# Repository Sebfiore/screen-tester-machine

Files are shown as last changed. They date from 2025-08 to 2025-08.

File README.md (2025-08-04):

# Screen Tester Machine  

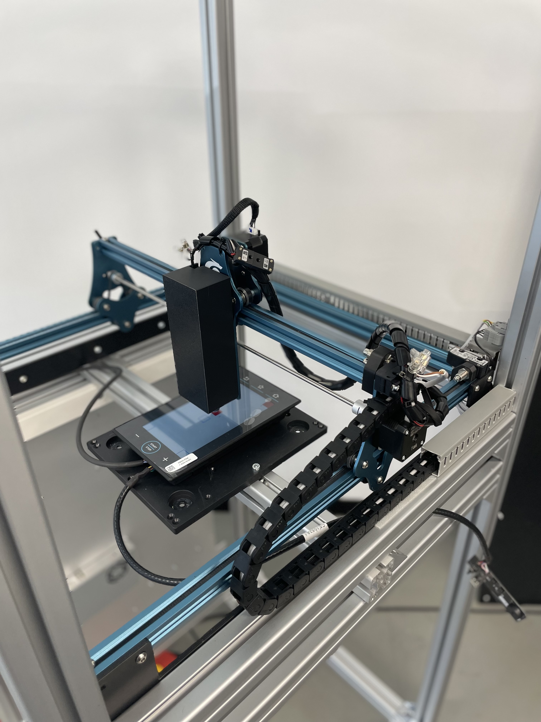
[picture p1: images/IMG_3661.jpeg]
System overview


## Overview

This is an interdisciplinary mechatronics project developed during an internship in the validation department of an Italian electronics company, in collaboration with the University of Padua. It automates the testing of capacitive touch displays by integrating mechanical, electronic, and embedded software components into a unified system.

The platform features multi-axis motion control using stepper motors and custom firmware running on an LPC1768 microcontroller.  
The firmware, written in embedded C, manages both the working routine and low-level stepper motor control.

The design covers all major functional areas of a mechatronic system:

- **Hardware**: Starting from a modified commercial multi-axis platform, the entire structure was redesigned using 3D models and assembled manually. Two commercial machines were evaluated—a 3D printer and a laser cutting machine. The latter was selected for the final build.
- **Electronics**: Custom drive electronics were developed to ensure reliability and flexibility, replacing the original laser machine’s control board. Two stepper drivers were interfaced with the LPC1768 controller.
- **Software**: Both machine routine logic and stepper motor control functions were developed. Special focus was placed on motor speed control. The final version supports a trapezoidal speed profile, with other options also available.

Ultimately, the core focus of the project is system integration: all components were developed independently, with continuous consideration of their role within the complete system. This is arguably the most critical and complex aspect of any mechatronic design.

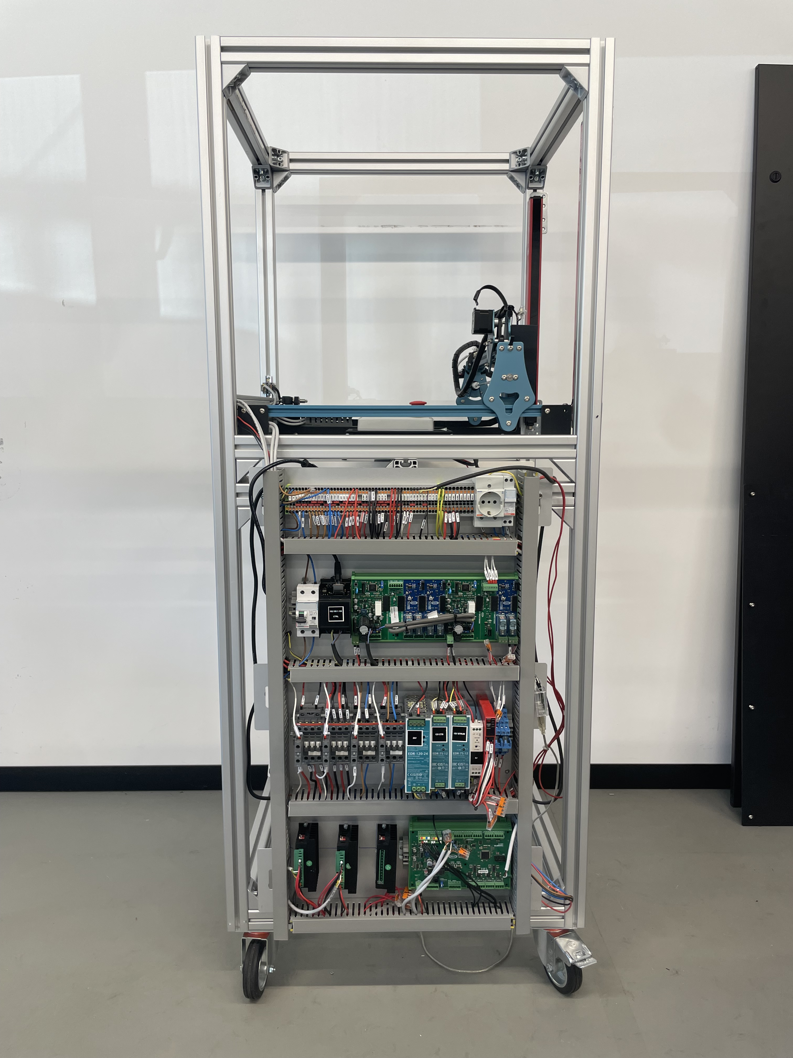
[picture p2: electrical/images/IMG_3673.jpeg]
System overview: Electrical subsystem with TB6600 drivers and LPC1768 control board.


## The Machine

The machine automates the validation process of capacitive touch displays after production. Each display normally requires manual testing—touching a series of points to verify functionality. This machine performs the validation process automatically.  
Future versions aim to further optimize validation by incorporating additional phases such as display programming and automatic color validation.

## Subsystems

### Mechanical

The `mechanical` folder contains descriptions of the system assemblies. Both 3D-printed and machined parts were used. The commercial laser cutter was modified and integrated into an aluminum extrusion frame. All components were designed in 3D prior to assembly.

A key innovation was the development of a compliant mechanism for the touch interface. The touch tip had to press against the display and then release—this was achieved using a solenoid acting on a 3D-printed compliant structure. This solution provided the required flexibility and tight tolerances in a single part.  
The previous traditional system relied on a spring and an aluminum guide, which were more expensive to manufacture and less precise.

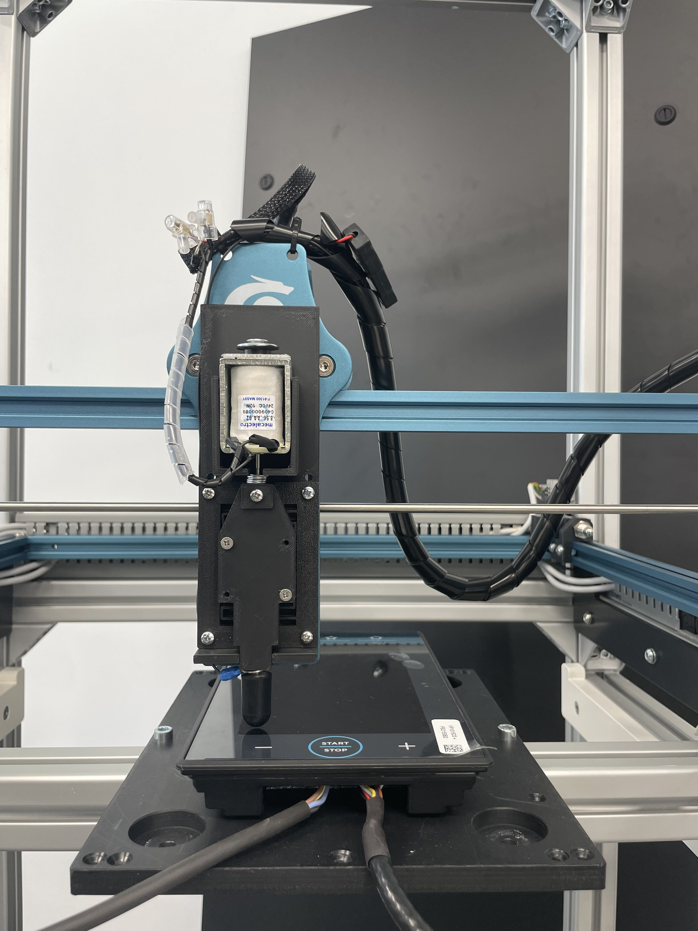
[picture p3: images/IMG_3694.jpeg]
Compliant touch mechanism


### Electrical

This subsystem handles actuation signaling, sensing, and power distribution:
- Dual TB6600 stepper driver control  
- Solenoid actuation with flyback protection  
- Software-selectable endstop inputs via multiplexer  
- Multiple power domains (24V, 12V, 5V) managed by the LPC1768 controller  

### Software / Firmware

The embedded software is written in **C** and runs on a custom LPC1768 (ARM Cortex-M3) controller. It provides real-time orchestration of motion, touch actuation, sensing, and test sequencing for touchscreen validation. See the dedicated section for more detail.

#### Outcomes
- Designed for extensibility: new test patterns, conditional logic, and additional sensors can be integrated without altering the core logic  
- Demonstrates real-time embedded programming, state-machine design, and system-level integration under resource constraints

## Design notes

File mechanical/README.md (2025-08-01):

# Mechanical Subsystem — Screen Tester Machine  

## 1. Introduction

The mechanical subsystem implements the physical interaction layer of the Screen Tester Machine. It comprises the complete structural assembly, interchangeable touch heads in two development stages (conceptual and realized), and a compliant mechanism implemented in two variants to mediate force or alignment. This document describes the design, evolution, and rationale behind each major mechanical element, emphasizing system integration, modularity, and functional trade-offs.

## 2. Overall Assembly

Figure 1: Complete mechanical assembly showing frame, motion stages, touch head interface, and integration points with electrical and actuation subsystems.

*Figure 1* presents the full assembly. The design integrates actuation (from the electrical subsystem), sensing, and the user-contact interface (touch head) into a coherent structure. Key sub-assemblies include the motion positioning stage, the mount for the touch head, compliant interface elements, and the structural frame that ensures repeatability and rigidity under load.

### 2.1 Objectives of the Mechanical Design

- Provide precise and repeatable positioning of the touch interface relative to the display under test.  
- Enable modular swapping and iteration of touch head designs without full system redesign.  
- Isolate and control interaction forces through compliant elements to mimic realistic touches while protecting the device under test.  
- Maintain manufacturability and rapid prototyping capability (e.g., via 3D printing) for iterative development.

## 3. Touch Head Design

The touch head is the contact interface that physically interacts with the capacitive display. Two versions were developed: a conceptual (drawn) version and a realized version using 3D printed components.

### 3.1 Version 1: Conceptual / Drawn Design

Version 1 exists as a detailed design drawing / CAD sketch. It defines:

- Geometry intended to emulate a fingertip or stylus contact patch  
- Mounting interface compatible with the positioning mechanism  
- Intended degrees of freedom and kinematic assumptions  
- Placeholder for compliance or cushioning (if any) in the conceptual stage  

This version served to validate form, fit, and the integration strategy before committing to fabrication.

### 3.2 Version 2: Realized 3D-Printed Touch Head

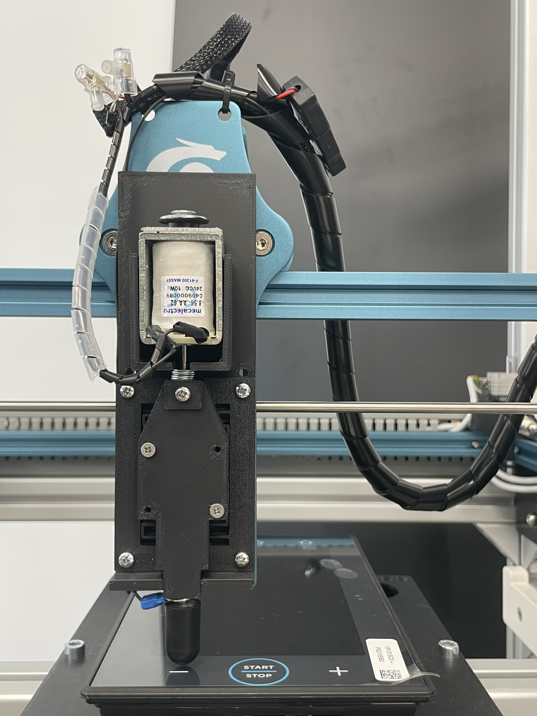
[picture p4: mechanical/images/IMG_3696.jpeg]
Figure 3: Photograph/render of the realized touch head (version 2) fabricated with 3D printed components, showing actual assembly and interface to the compliant mechanism.


Version 2 is the physically fabricated iteration based on the initial concept. Key characteristics:

- **Material:** PLA
- **Post-processing:** (e.g., smoothing, fitting, inserts)  

This realized head was used in empirical testing to assess contact consistency, durability, and repeatability.

## 4. Compliant Mechanism

A compliant mechanism is used to modulate interaction force and absorb minor misalignments between the rigid motion system and the touch surface. Two versions of this mechanism were developed to explore different trade-offs in stiffness, travel, and complexity.

### 4.1 Version 1: Initial Compliant Design

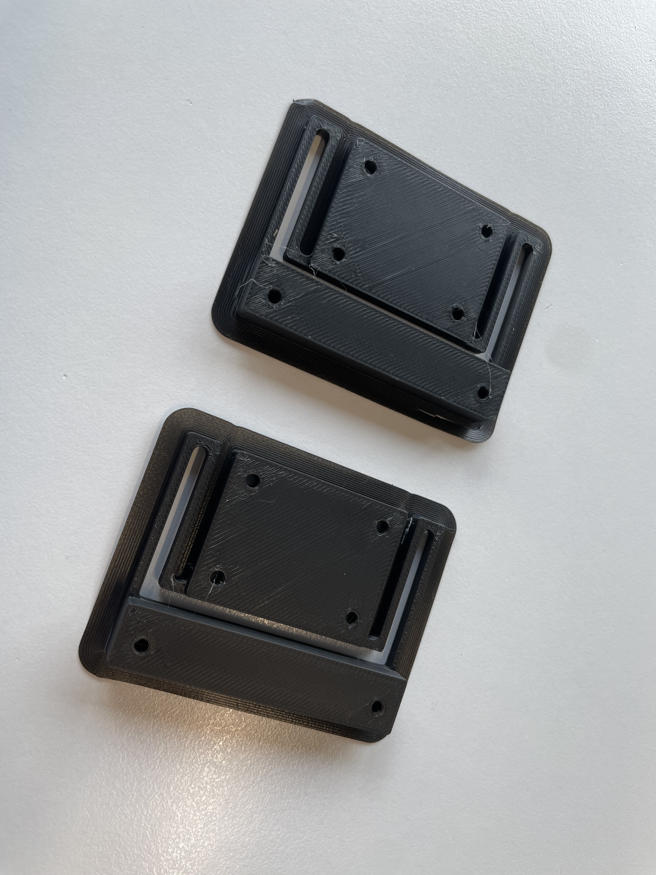
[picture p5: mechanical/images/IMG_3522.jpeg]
Figure 4: Compliant mechanism version 1, illustrating flexural elements and expected deflection under load.


Version 1 utilizes a basic flexure-based geometry designed to allow controlled axial compliance while maintaining lateral constraint. It proved to be too stiff for the scope.

### 4.2 Version 2: Refined Compliant Mechanism

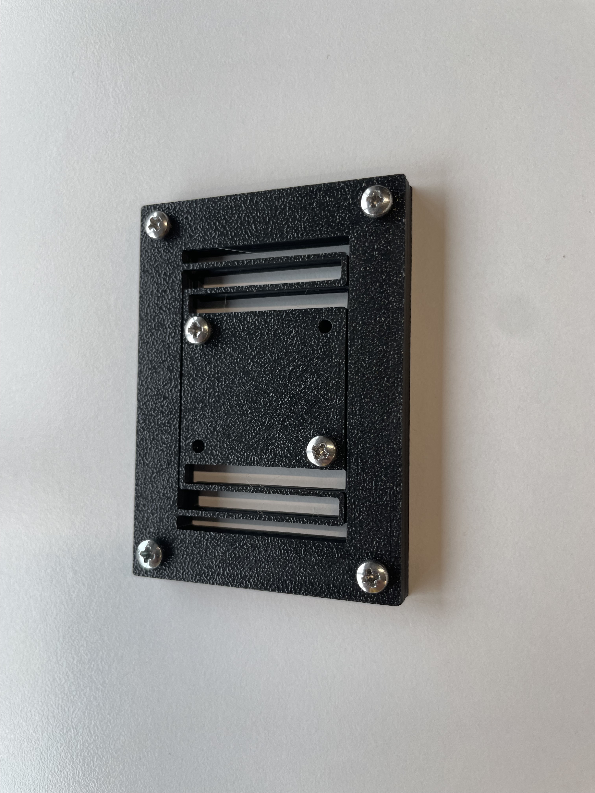
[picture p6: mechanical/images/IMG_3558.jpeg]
Figure 5: Refined compliant mechanism version 2 showing enhancements.


Version 2 represents an evolved design, incorporating lessons from version 1:

- Decreased stiffness
- Integration of mounting features to reduce assembly complexity  

This iteration aimed to balance precision of actuation with robustness over repeated test cycles.

## 5. Mechanical Integration and Interfaces

The touch head and compliant mechanism are mounted to the primary motion stage. The interface between these subsystems was designed for:

- **Quick interchangeability:** Mechanical interfaces (e.g., dovetail, screw boss, snap-fit) allow swapping in the field.  
- **Alignment tolerance:** Compliant elements compensate for small misalignments without degrading measurement fidelity.  

## 6. Design Considerations

- **Prototyping speed:** 3D printing enabled rapid iteration from version 1 to 2 for both touch heads and compliant elements.  
- **Repeatability vs. compliance:** Trade-offs were explicitly evaluated; too much compliance reduces positional accuracy, too little risks damaging the display.  
- **Modularity:** Subsystems are decoupled to allow independent redesign (e.g., new touch head geometries) without retooling the entire assembly.  
- **Manufacturability:** Feature sizes, overhangs, and assembly clearances were constrained by typical FDM printer capabilities.

## 7. Validation Strategy (Descriptive)

Validation of the mechanical subsystem encompassed:

- **Geometric verification:** Ensuring fabricated parts adhered to design dimensions within expected tolerances.  
- **Force profiling:** Measuring the actual contact forces delivered through the compliant mechanism and comparing to target touch profiles.  
- **Durability testing:** Cycling the touch head/compliant interface to observe wear or degradation.  
- **Alignment robustness:** Introducing deliberate offset and measuring if the compliant mechanism compensated without system failure.  
- **Interchangeability checks:** Swapping touch heads and confirming consistent mounting and functional behavior.

## 9. Future Work / Extensions

- Design of alternative touch head geometries (e.g., soft-touch, multi-point)  
- Multi-material compliant mechanisms to introduce tunable damping  
- Embedding sensors (force/pressure) within the compliant interface for closed-loop feedback  

## 10. Conclusion

The mechanical subsystem provides a flexible, modular, and experimentally grounded physical interface for the Screen Tester Machine. Through iterative development of touch heads and compliant mechanisms, the design balances precise actuation, repeatable contact, and protection of the device under test, fulfilling the core goals of the university project.

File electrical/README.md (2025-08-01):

# Electrical Subsystem — Screen Tester Machine  

## 1. Introduction

This document describes the electrical subsystem, its architecture, and its role within the broader system. The focus is on functional description, component interaction, and design rationale.

## 2. System Overview

The electrical subsystem interfaces the mechanical actuation, sensing, and control logic. Its primary responsibilities are:

- Driving two stepper motors to position the stylus/probe via TB6600 drivers  
- Actuating a solenoid for discrete tap interactions  
- Sensing positional limits through endstops with selectable inputs  
- Distributing and conditioning multiple power domains  
- Centralized coordination through a custom LPC1768-based controller  

Control logic, signal multiplexing, and sequencing are consolidated on the custom LPC1768 board. The board issues actuation commands, selects among endstop inputs in software, and orchestrates the timing of movements and interactions.

## 3. Embedded Visual Reference

Figure 1: Electrical subsystem layout including the two TB6600 stepper drivers (bottom left), the custom LPC1768 control board (bottom right), power distribution, and endstop multiplexing.

*Figure 1* shows the physical arrangement of key electrical components and provides contextual insight into signal flow, power routing, and subsystem placement.

## 4. Component Description

### 4.1 Microcontroller and Control Logic

The core intelligence resides on a custom board based on the **LPC1768** microcontroller. This board:

- Generates digital control signals for the stepper drivers (pulse, direction, enable)  
- Drives the solenoid actuator directly via a digital output  
- Samples endstop states through a software-controlled multiplexer  
- Manages synchronization and sequencing for test routines  

Software selection of multiplexer channels allows flexible polling of multiple endstop sensors using minimal input pins.

### 4.2 Stepper Motor Interface

Two stepper motors are interfaced via **TB6600** drivers. Each driver receives:

- **PUL (Pulse):** Step increment signal  
- **DIR (Direction):** Movement direction  
- **ENA (Enable):** Gate to enable/disable outputs  

These signals originate from the LPC1768 digital outputs and are logic-compatible with the TB6600 modules, assuming a shared 5V reference. Signal integrity is maintained by appropriate routing and respecting timing requirements inherent to the driver.

### 4.3 Solenoid Actuation

The solenoid provides discrete tactile interactions (e.g., taps). It is driven directly from a digital output on the LPC1768 board. A **flyback diode** is placed in parallel with the coil to suppress inductive voltage spikes when the drive is released, protecting the driving circuitry.

### 4.4 Endstop Sensing

Endstop sensors are multiplexed: a software-controlled **multiplexer** selects which endstop is routed back to the LPC1768 for sampling. This reduces pin usage while retaining the ability to monitor multiple limit switches. Defined idle logic levels are ensured via pull-ups/pull-downs, and debounce logic in firmware stabilizes mechanical chatter.

## 5. Power Architecture

The electrical subsystem employs distinct voltage domains to meet component requirements:

- **24V Domain:** Powers the LPC1768-based control board and the touchscreen under test.  
- **12V Domain:** Supplies the solenoid actuator.  
- **5V Domain:** Supplies logic levels for the TB6600 driver inputs and any ancillary digital circuits.

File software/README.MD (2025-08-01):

# Screen Tester Machine - Software Documentation

A student project developing automated testing software for capacitive touchscreen validation using embedded systems programming.

## 🎓 Project Overview

This project explores the software challenges involved in creating an automated touchscreen testing system. The software component focuses on real-time motion control, command processing, and test sequence execution using embedded C programming on the LPC1768 microcontroller platform.

## 🎯 Software Objectives

The software development addresses several key engineering challenges:
- **Real-time Control**: Implementing precise stepper motor control with timing constraints
- **Command Processing**: Designing a robust serial communication protocol
- **State Management**: Managing complex system states and error conditions
- **Modular Architecture**: Creating maintainable and extensible embedded code

## 💻 Software Architecture

### Core Components

**Motion Control Engine**
- Implements stepper motor control algorithms with acceleration/deceleration profiles
- Manages multi-axis coordination for complex gesture simulation
- Handles real-time positioning feedback and error correction
- Uses interrupt-driven timing for precise step generation

**Command Parser Module**
- Processes incoming serial commands using finite state machine approach
- Implements command validation and parameter checking
- Manages command queue for sequential execution
- Provides error reporting and status feedback

**Test Sequence Engine**
- Executes programmed test routines with precise timing control
- Supports conditional logic and loop structures
- Manages test state persistence and recovery
- Integrates logging functionality for result capture

### Implementation Insights

**Microcontroller Platform: LPC1768**
- ARM Cortex-M3 architecture provides sufficient processing power
- Multiple timer peripherals enable precise motion control timing
- UART interface handles serial communication at 115200 baud
- GPIO pins control stepper drivers and read endstop sensors

**Real-Time Considerations**
- Uses hardware timers for step pulse generation (sub-millisecond precision)
- Implements priority-based interrupt handling for motion control
- Employs circular buffers for command queuing and data logging
- Manages memory allocation for embedded environment constraints

## 🔧 Technical Implementation

### Motion Control Algorithm
The software implements trapezoidal velocity profiles:
- Acceleration phase with configurable ramp rates
- Constant velocity phase for smooth motion
- Deceleration phase with position prediction
- Real-time adjustment based on endstop feedback

## 📊 Software Features Developed

**Command Set Implementation**
- Movement commands with coordinate validation
- System control (home, reset, status)
- Configuration commands for calibration

**Safety Features**
- Limit switch monitoring and emergency stops
- Command validation to prevent mechanical damage

## 🛠️ Development Challenges Addressed

### Timing Precision
- Achieving sub-millisecond timing accuracy for touch simulation
- Balancing interrupt priorities to prevent motion jitter
- Implementing smooth acceleration curves in real-time

### Communication Reliability
- Handling serial communication errors and timeouts
- Implementing command acknowledgment system
- Managing buffer overflow conditions

### System Integration
- Coordinating multiple hardware subsystems
- Managing power sequencing and initialization
- Implementing diagnostic capabilities for debugging

## 📈 Technical Achievements

**Performance Metrics Achieved:**
- Position accuracy: ±0.1mm repeatability through software calibration
- Command response latency: <10ms average processing time
- Continuous operation capability with error recovery mechanisms
- Modular code structure enabling easy feature additions

**Learning Outcomes:**
- Embedded C programming for real-time applications
- Interrupt-driven system design and timing analysis
- State machine design for complex system control
- Hardware abstraction layer development

## 🔍 Code Structure

```
firmware/
├── src/
│   ├── main.c              # Main application loop
│   ├── motion_control.c    # Stepper motor algorithms
│   ├── command_parser.c    # Serial protocol handling
│   ├── test_engine.c       # Test sequence execution
│   └── hardware_hal.c      # Hardware abstraction
├── include/
│   ├── system_config.h     # Configuration parameters
│   ├── commands.h          # Command definitions
│   └── motion_types.h      # Data structures

## 🎯 Educational Value

This project demonstrates practical application of:
- **Embedded Systems Programming**: Low-level hardware control and real-time constraints
- **Communication Protocols**: Designing robust serial interfaces
- **Software Architecture**: Creating modular, maintainable embedded code
- **System Integration**: Coordinating software with mechanical and electrical components

The software component showcases the complexity involved in creating reliable automation systems and provides hands-on experience with industrial control programming techniques.

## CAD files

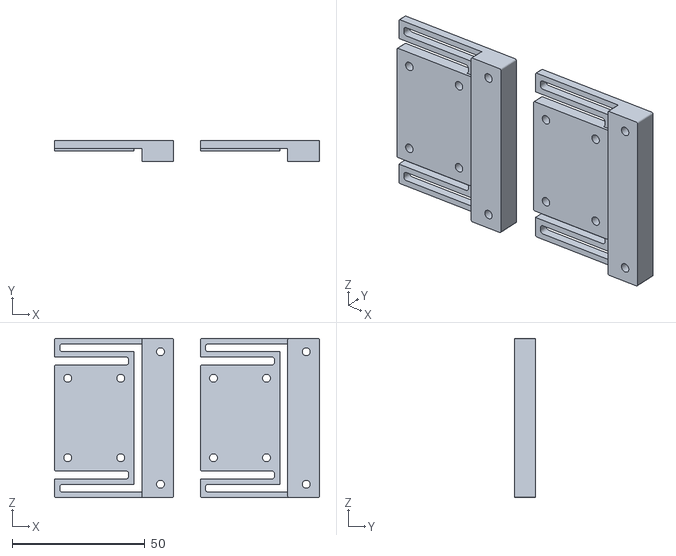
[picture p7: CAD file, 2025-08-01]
mechanical/3d_printed_parts/compliant_mechanism_v3.stl
100.0 x 8.00 x 60.0

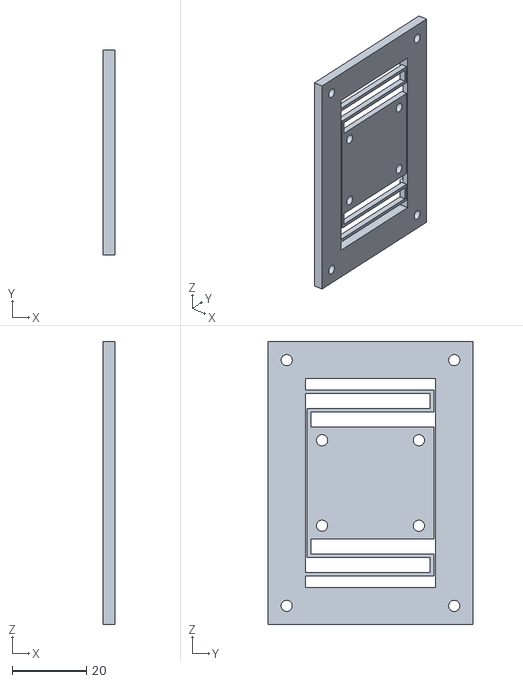
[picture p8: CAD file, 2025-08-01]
mechanical/3d_printed_parts/compliant_mechanism_v3/Compliant element.stl
3.20 x 55.0 x 76.0

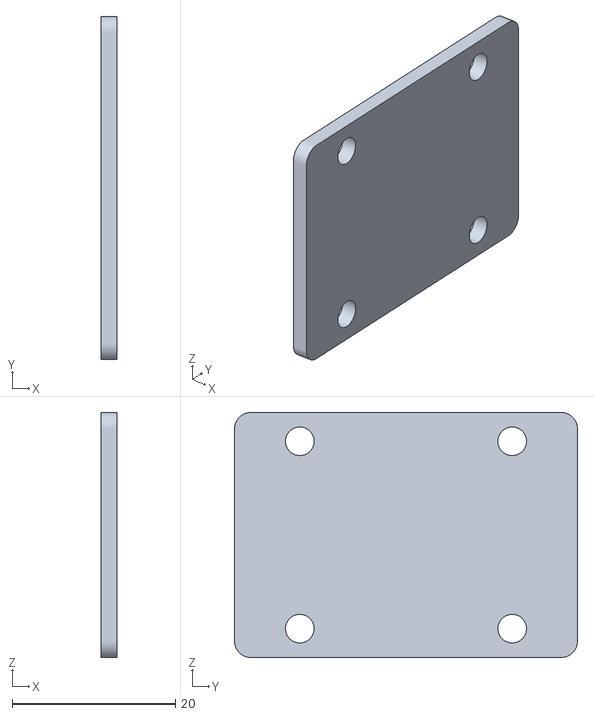
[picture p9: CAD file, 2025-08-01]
mechanical/3d_printed_parts/compliant_mechanism_v3/p1.stl
2.00 x 42.0 x 30.0

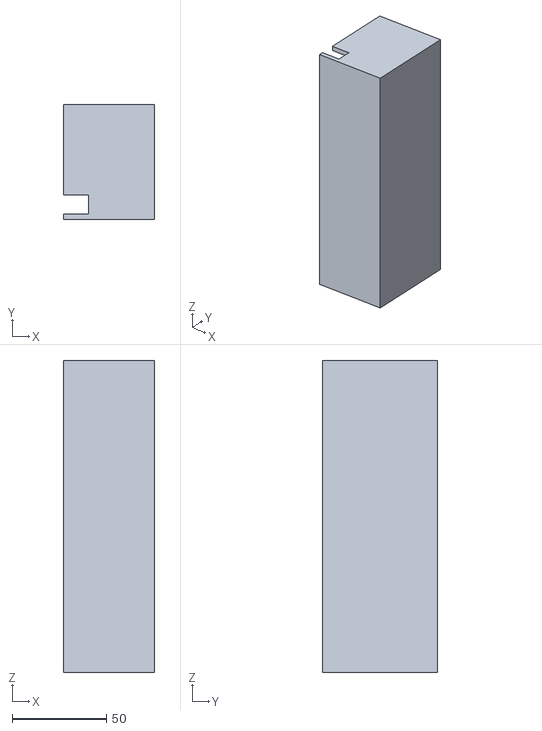
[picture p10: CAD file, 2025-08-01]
mechanical/3d_printed_parts/cover.stl
48.0 x 61.0 x 165.5

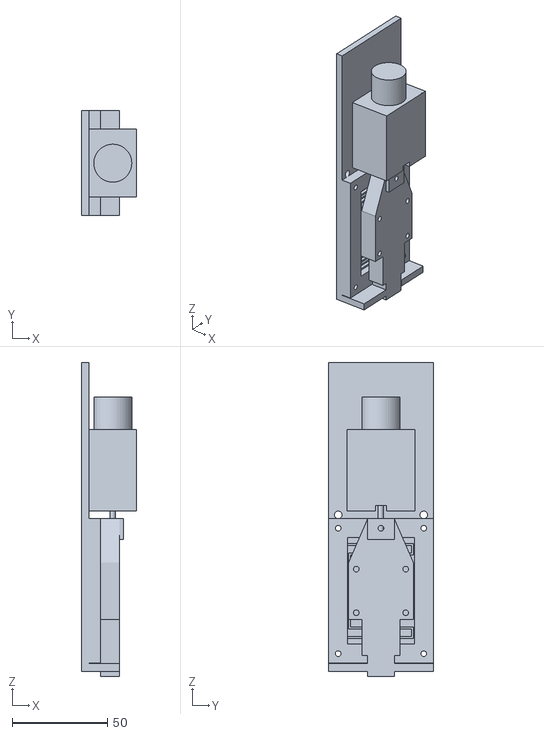
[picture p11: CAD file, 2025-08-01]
mechanical/3d_printed_parts/Solenoide compliant sysem.stl
29.0 x 55.0 x 165.2

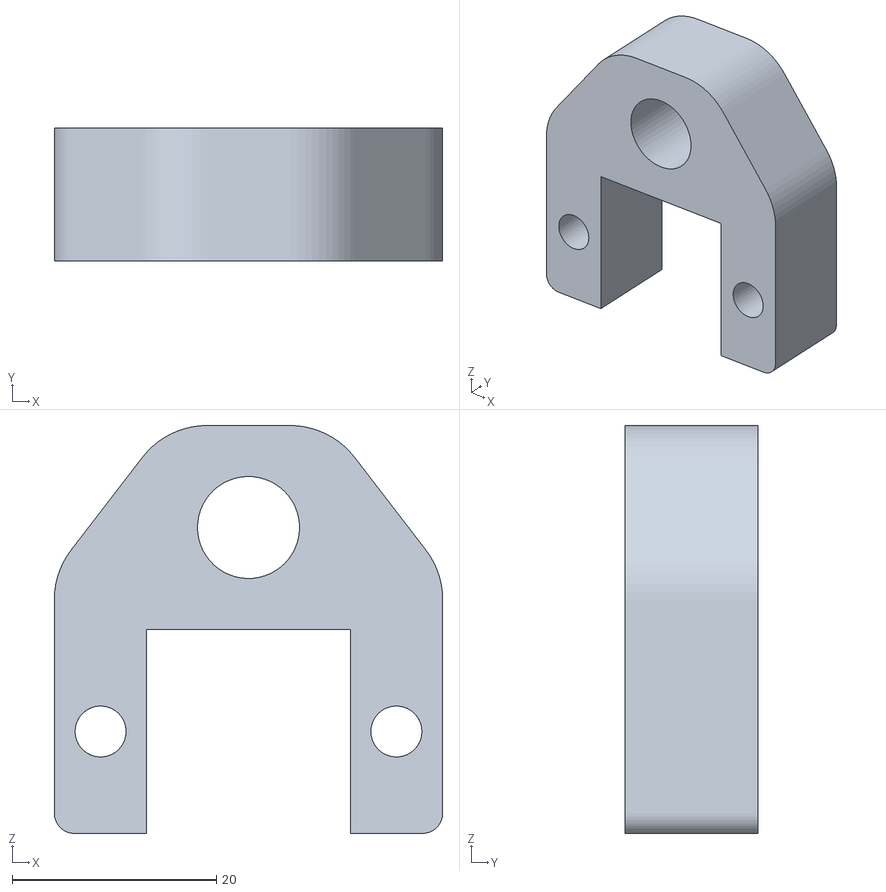
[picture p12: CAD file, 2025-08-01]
mechanical/3d_printed_parts/Supporto finecorsa X v1.stl
38.1 x 13.0 x 40.0

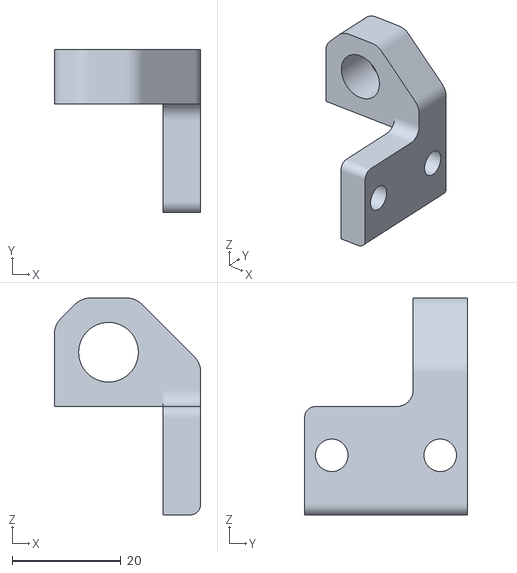
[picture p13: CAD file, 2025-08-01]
mechanical/3d_printed_parts/Supporto finecorsa Y.stl
27.0 x 30.0 x 40.0

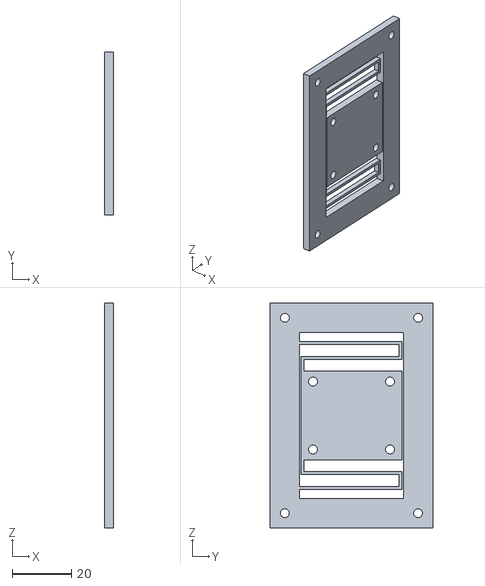
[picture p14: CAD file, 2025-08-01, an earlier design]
mechanical/3d_printed_parts/compliant_mechanism_v1.stl
3.00 x 55.0 x 76.0

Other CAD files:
mechanical/touch_head_assembly/compliant_component_v1.f3d
mechanical/touch_head_assembly/compliant_component_v2.f3d
mechanical/touch_head_assembly/v1.f3d
mechanical/touch_head_assembly/v2_compliant.f3d

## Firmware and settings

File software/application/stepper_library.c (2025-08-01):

// First version of the stepper library
// Initially used speed arrays to avoid divisions at runtime
// The new version uses timers instead

#include "stepper_library.h"
#include "smu.h"

#define TIMEOUT_TRAFFICO_CANBUS_MS (2000) // 2 seconds

void _PRINT(int x, const char *m)
{
    _DBD32(x); // Print integer x (32-bit decimal)
    _DBG(m);   // Print message string
}

// Stepper motor drive section
#define ARR_COUNT(a) (sizeof(a) / sizeof(a[0]))               // Macro to count array elements
#define MAX_NUM_OF_BLOCKS ((ARR_COUNT(speed_array)-1)*2 + 1) // Acceleration and deceleration blocks

// Timer assumptions:
// CCLK/4 -> 25 MHz, prescale -> 1.5625 MHz
// Half-step mode: 400 pulses/rotation
// Pulley diameter: 11 mm -> 34.6 mm circumference
// Timer Match 7812 -> 200 Hz -> 100 Hz pulses -> 0.25 RPM -> ~8.65 mm/s
// Prescaler 140 -> ~11.2 kHz -> ~5.58 kHz pulses -> 14.0 RPM -> ~483 mm/s

#define SPEED_MIN (speed_array[0])
#define NUMBER_OF_STEPS_PER_BLOCK 256
#define SPEED_LEVELS 8
#define K_STEPS_PER_SPEED 500000

// Calibrated at 30V. Increase voltage to increase speed.
#define SPEED_MIN_uS_anycubic 10000
#define SPEED_MAX_uS_anycubic 250
#define SPEED_MIN_uS_laser 20000
#define SPEED_MAX_uS_laser 480

int SPEED_MIN_uS = 0;
int SPEED_MAX_uS = 0;

int speed_array[SPEED_LEVELS] = { };
int steps_array[SPEED_LEVELS - 1] = { };
int steps_integral[SPEED_LEVELS - 1] = { };

void create_arrays()
{
    SPEED_MIN_uS = SPEED_MIN_uS_laser;
    SPEED_MAX_uS = SPEED_MAX_uS_laser;

    speed_array[0] = SPEED_MIN_uS;
    speed_array[SPEED_LEVELS - 1] = SPEED_MAX_uS;

    float last = (1 / (float)speed_array[0]);
    float delta = ((1 / (float)speed_array[SPEED_LEVELS - 1]) - last) / (SPEED_LEVELS - 1);

    _DBG("ARRAYS:\n");
    _DBG("Speed: ");

    for (int fd = 1; fd < SPEED_LEVELS - 1; fd++) {
        last += delta;
        speed_array[fd] = 1 / last + 0.5;
        _PRINT(speed_array[fd], ", ");
    }
    _DBG("\n");

    _DBG("Steps: ");
    for (int fd = 0; fd < SPEED_LEVELS - 1; fd++) {
        steps_array[fd] = K_STEPS_PER_SPEED / (float)speed_array[fd] + 0.5;
        _PRINT(steps_array[fd], ", ");
    }
    _DBG("\n");

    _DBG("Integral: ");
    int sum = 0;
    for (int fd = 0; fd < SPEED_LEVELS - 1; fd++) {
        sum += steps_array[fd];
        steps_integral[fd] = sum * 2;
        _PRINT(steps_integral[fd], ", ");
    }
    _DBG("\n");
}

// Structs for axis movement

typedef struct {
    uint8_t axis;       // 0=x, 1=y, 2=z
    uint8_t mode;       // 0=accel, 1=cruise, 2=decel
    uint8_t next_speed_level;
    uint8_t stop;
    uint32_t timer_count;
} st_pacekeeper;

st_pacekeeper pace[MAX_NUM_OF_BLOCKS * 3];
volatile int pace_count;
volatile int pace_index;
static LPC_TIM_TypeDef *const get_timers[] = { LPC_TIM0, LPC_TIM1, LPC_TIM2 };
volatile int irq_count_A, irq_count_B;

typedef struct {
    uint32_t tot_steps;
    uint32_t divisor;
    uint32_t remainder;
    uint32_t remaining_steps;
    uint32_t divisor_count;
    int32_t remainder_count;
} st_axis;

st_axis xax, yax, zax;

typedef struct {
    uint32_t accel;
    uint32_t cruise;
    uint32_t decel;
    uint32_t cruise_steps_count;
    uint32_t steps_count;
} st_accel;

st_accel accel;

void prepare_axis(st_axis *ax, uint32_t count, uint32_t max)
{
    ax->tot_steps = count;
    ax->divisor = max / count;
    ax->remainder = max % count;
    ax->remaining_steps = count;
    ax->divisor_count = (ax->divisor + 1) / 2;
    ax->remainder_count = -(int32_t)count / 2;
}

void run(int32_t x, int32_t y, int32_t z)
{
    // Reverse directions
    x = -x;
    y = -y;

    int x_dir = 0, y_dir = 0, z_dir = 0;
    if (x < 0) { x = -x; x_dir = 1; }
    if (y < 0) { y = -y; y_dir = 1; }
    if (z < 0) { z = -z; z_dir = 1; }

    x *= 2;
    y *= 2;
    z *= 2;

    // Set directions (X, Y, Z)
    if (x_dir == 0) GPIO_SetValue(1, 1<<28);
    else GPIO_ClearValue(1, 1<<28);

    if (y_dir != 0) GPIO_SetValue(1, 1<<22);
    else GPIO_ClearValue(1, 1<<22);

    if (z_dir != 0) GPIO_SetValue(4, 1<<28);
    else GPIO_ClearValue(4, 1<<28);

    uint32_t count_vec[] = { x, y, z };
    int max_ax;
    if (x > y) max_ax = (x > z) ? 0 : 2;
    else max_ax = (y > z) ? 1 : 2;

    prepare_axis(&xax, x, count_vec[max_ax]);
    prepare_axis(&yax, y, count_vec[max_ax]);
    prepare_axis(&zax, z, count_vec[max_ax]);

    if (count_vec[max_ax] <= (uint32_t)steps_integral[0]) {
        accel.accel = 0;
        accel.cruise = 1;
        accel.decel = 0;
        accel.cruise_steps_count = count_vec[max_ax];
    } else {
        accel.accel = 0;
        for (int yy = ARR_COUNT(steps_integral) - 1; yy >= 0; yy--) {
            if (count_vec[max_ax] > (uint32_t)steps_integral[yy]) {
                accel.accel = yy + 1;
                break;
            }
        }
        accel.cruise = 1;
        accel.decel = accel.accel;
        accel.cruise_steps_count = count_vec[max_ax] - steps_integral[accel.accel - 1];
    }
    accel.steps_count = 0;
}

int single_step(st_axis *ax)
{
    if (ax->divisor_count == 1) {
        ax->remainder_count += ax->remainder;
        if (ax->remainder_count > 0) {
            ax->remainder_count -= ax->tot_steps;
            ax->divisor_count = ax->divisor + 1;
        } else ax->divisor_count = ax->divisor;
        ax->remaining_steps--;
        return 1;
    } else {
        ax->divisor_count--;
    }
    return 0;
}

volatile int is_running = 0;
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

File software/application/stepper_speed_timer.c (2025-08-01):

#include "stepper_speed_timer.h"

// This file defines stepper speed functions.
// Other utility functions (e.g., for calibration or zeroing) that use these routines will include this library.
// Goal: set speed as steps per second (consider using mm/s).
// Reactivate interrupts when needed.

#include "LPC17xx.h"

typedef struct {
    int total_steps;
    int previous_count;
    int remaining_steps;
    int current_speed;       // Steps per second, initialized to min speed
    int delta_speed;
    int min_speed;           // Steps per second
    int max_speed;           // Steps per second
    int accel_steps;         // Steps during acceleration
    volatile int phase;      // Must be volatile: used in ISR. 0=accel, 1=cruise, 2=decel, 4=done
    int update_speed_flag;
} ax_state;

ax_state x_ax;
ax_state y_ax;

int done_x = 0;
int done_y = 0;

int tim0_update = 0;
int tim1_update = 0;

void set_directions(int xs, int ys) {
    if (xs > 0)
        GPIO_SetValue(X_PORT, X_DIR_PIN);   // X direction
    else
        GPIO_ClearValue(X_PORT, X_DIR_PIN);

    if (ys < 0)
        GPIO_SetValue(Y_PORT, Y_DIR_PIN);   // Y direction
    else
        GPIO_ClearValue(Y_PORT, Y_DIR_PIN);
}

void init_timer0(uint32_t frequency_hz) {
    // Frequency of interrupts = steps per second
    uint32_t pclk = SystemCoreClock / 4;           // LPC1768 typical: 100 MHz / 4 = 25 MHz
    uint32_t match_value = pclk / frequency_hz;

    LPC_TIM0->MR0 = match_value;
    LPC_TIM0->MCR = 3;      // Interrupt and reset on MR0
    LPC_TIM0->TCR = 1;      // Enable timer
    NVIC_EnableIRQ(TIMER0_IRQn);
}

void init_timer1(uint32_t frequency_hz) {
    uint32_t pclk = SystemCoreClock / 4;
    uint32_t match_value = pclk / frequency_hz;

    LPC_TIM1->MR0 = match_value;
    LPC_TIM1->MCR = 3;
    LPC_TIM1->TCR = 1;
    NVIC_EnableIRQ(TIMER1_IRQn);
}

void run_stepper_timer(int xs, int ys, int x_speed_min, int y_speed_min, int x_speed_max, int y_speed_max) {
    // Start a move with acceleration, cruise, and deceleration phases.
    // Speed parameters could be constants, but using arguments allows calibration.

    set_directions(xs, ys);

    // --- X AXIS SETUP ---
    x_ax.total_steps     = abs(xs);
    x_ax.remaining_steps = abs(xs);
    x_ax.current_speed   = x_speed_min;
    x_ax.min_speed       = x_speed_min;
    x_ax.max_speed       = x_speed_max;
    x_ax.delta_speed     = X_DELTA_SPEED;
    x_ax.previous_count  = 0;
    x_ax.phase           = 0;
    x_ax.accel_steps     = 0;
    x_ax.update_speed_flag = 0;

    // --- Y AXIS SETUP ---
    y_ax.total_steps     = abs(ys);
    y_ax.remaining_steps = abs(ys);
    y_ax.current_speed   = y_speed_min;
    y_ax.min_speed       = y_speed_min;
    y_ax.max_speed       = y_speed_max;
    y_ax.delta_speed     = Y_DELTA_SPEED;
    y_ax.previous_count  = 0;
    y_ax.phase           = 0;
    y_ax.accel_steps     = 0;
    y_ax.update_speed_flag = 0;

    // --- X acceleration calculations ---
    int x_acceleration_steps = (x_ax.max_speed - x_ax.min_speed) / X_DELTA_SPEED;

    // Case: Not enough distance to reach max speed
    if (x_ax.total_steps <= (x_acceleration_steps * 2)) {
        x_ax.accel_steps = x_ax.total_steps / 2;
        x_ax.max_speed = x_ax.min_speed + (X_DELTA_SPEED * x_ax.accel_steps);
    } else {
        x_ax.accel_steps = x_acceleration_steps;
    }

    // --- Y acceleration calculations ---
    int y_acceleration_steps = (y_ax.max_speed - y_ax.min_speed) / Y_DELTA_SPEED;

    if (y_ax.total_steps <= (y_acceleration_steps * 2)) {
        y_ax.accel_steps = y_ax.total_steps / 2;
        y_ax.max_speed = y_ax.min_speed + (Y_DELTA_SPEED * y_ax.accel_steps);
    } else {
        y_ax.accel_steps = y_acceleration_steps;
    }

    tim0_update = x_ax.current_speed;
    tim1_update = y_ax.current_speed;

    // Set steps per second (Hz) for both timers
    init_timer0(x_ax.current_speed);
    init_timer1(y_ax.current_speed);

    // Wait until both axes complete their motion
    while (x_ax.phase != 4 || y_ax.phase != 4) {
        // Do nothing; volatile flags will be updated by the ISRs
    }
}

// --- TIMER0 ISR (X Axis) ---
void TIMER0_IRQHandler(void) {
    if (LPC_TIM0->IR & 1) {
        LPC_TIM0->IR = 1;  // Clear interrupt

        if (x_ax.phase != 4) {
            GPIO_SetValue(X_PORT, X_PULSE_PIN);     // Pulse HIGH
            for (volatile int i = 0; i < 50; i++);   // Short delay (≥5 µs)
            GPIO_ClearValue(X_PORT, X_PULSE_PIN);    // Pulse LOW
            x_ax.remaining_steps--;

            // Acceleration
            if (x_ax.current_speed < x_ax.max_speed && x_ax.phase == 0) {
                x_ax.current_speed += X_DELTA_SPEED;
                tim0_update = x_ax.current_speed;
            } else if (x_ax.phase == 0) {
                x_ax.phase = 1;  // Switch to cruise
            }

            // Cruise → deceleration
            if (x_ax.phase == 1 && x_ax.remaining_steps <= x_ax.accel_steps) {
                x_ax.phase = 2;
            }

            // Deceleration
            if (x_ax.current_speed > x_ax.min_speed && x_ax.phase == 2) {
                x_ax.current_speed -= X_DELTA_SPEED;
                tim0_update = x_ax.current_speed;
            }

            // End of motion
            if (x_ax.remaining_steps <= 0) {
                x_ax.phase = 4;
            }
        }
    }

    if (tim0_update < 1) tim0_update = 1;
    LPC_TIM0->MR0 = (SystemCoreClock / 4) / tim0_update;
    NVIC_ClearPendingIRQ(TIMER0_IRQn);
}

// --- TIMER1 ISR (Y Axis) ---
void TIMER1_IRQHandler(void) {
    if (LPC_TIM1->IR & 1) {
        LPC_TIM1->IR = 1;  // Clear interrupt

        if (y_ax.phase != 4) {
            GPIO_SetValue(Y_PORT, Y_PULSE_PIN);     // Pulse HIGH
            for (volatile int i = 0; i < 50; i++);   // Short delay
            GPIO_ClearValue(Y_PORT, Y_PULSE_PIN);    // Pulse LOW
            y_ax.remaining_steps--;

            // Acceleration
            if (y_ax.current_speed < y_ax.max_speed && y_ax.phase == 0) {
                y_ax.current_speed += Y_DELTA_SPEED;
                tim1_update = y_ax.current_speed;
            } else if (y_ax.phase == 0) {
                y_ax.phase = 1;  // Switch to cruise
            }

            // Cruise → deceleration
            if (y_ax.phase == 1 && y_ax.remaining_steps <= y_ax.accel_steps) {
                y_ax.phase = 2;
            }

            // Deceleration
            if (y_ax.current_speed > y_ax.min_speed && y_ax.phase == 2) {
                y_ax.current_speed -= Y_DELTA_SPEED;
                tim1_update = y_ax.current_speed;
            }

            // End of motion
            if (y_ax.remaining_steps <= 0) {
                y_ax.phase = 4;
            }
        }
    }

    if (tim1_update < 1) tim1_update = 1;
    LPC_TIM1->MR0 = (SystemCoreClock / 4) / tim1_update;
    NVIC_ClearPendingIRQ(TIMER1_IRQn);
}

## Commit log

2025-08-01 added mechanical documentation
    [Compliant element.stl, Solenoide compliant sysem.stl, Supporto finecorsa X v1.stl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]
2025-08-02 added complete assembly
